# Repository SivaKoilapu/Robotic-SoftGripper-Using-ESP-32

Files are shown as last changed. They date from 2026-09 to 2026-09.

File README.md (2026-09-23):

# ESP32 IoT Robotic Arm Soft Gripper

An IoT-controlled robotic arm featuring a continuous-rotation pan/tilt base and a custom three-finger, tendon-driven mechanical soft gripper. The system is driven by an ESP32 and controlled remotely via the Blynk IoT platform.

## ⚙️ Hardware Architecture
* **Microcontroller:** ESP32
* **Actuation (Pan/Tilt):** Continuous Rotation Servos
* **Actuation (Gripper):** N20 Micro Gearmotor with Magnetic Encoder
* **Motor Driver:** TB6612FNG (For N20 bidirectional control)
* **Gripper Mechanism:** 3D-printed TPU mechanically-driven soft fingers, actuated by the N20 motor rotating a worm gear and follower.

## 💻 Software & Control Logic
The firmware is written in C++ and leverages `BlynkSimpleEsp32` for remote telemetry and control.

* **Asymmetric Joystick Mapping (Tilt Arm):** Continuous servos fighting gravity require highly specific PWM signals. The tilt arm uses an asymmetric mapping curve to distinguish between lifting against gravity, active braking, and powered descent.
* **Closed-Loop Gripper Control:** The N20 motor utilizes a custom PID-style interrupt loop reading the quadrature encoder. This allows the system to target precise rotational clicks (e.g., exactly 3 turns to fully close the tendons) and actively lock the brakes when target is reached.

## 📂 Repository Contents
* `/CAD` - Contains the SolidWorks part and assembly files (`.SLDPRT`, `.SLDASM`) for the arm and the TPU soft gripper, alongside `.STL` exports for immediate 3D printing.
* `/Firmware` - The Arduino IDE / PlatformIO compatible C++ code for the ESP32.

## 🚀 Setup & Installation
1. Flash the firmware to the ESP32.
2. Update the `ssid`, `pass`, and `BLYNK_AUTH_TOKEN` variables with your local credentials.
3. In the Blynk App, configure the datastreams:
   * **V0 (Joystick X):** Map to `-100 to 100` (Pan Base)
   * **V1 (Joystick Y):** Map to `-100 to 100` (Tilt Arm)
   * **V2 (Switch):** Map to `0 and 100` (Gripper Open/Close)

---
**Team:**<br> 
-Harshit Gupta<br>
-Kanav Gupta<br>
-SivaSankara Dasu Koilapu<br>
-Nikita Chitra

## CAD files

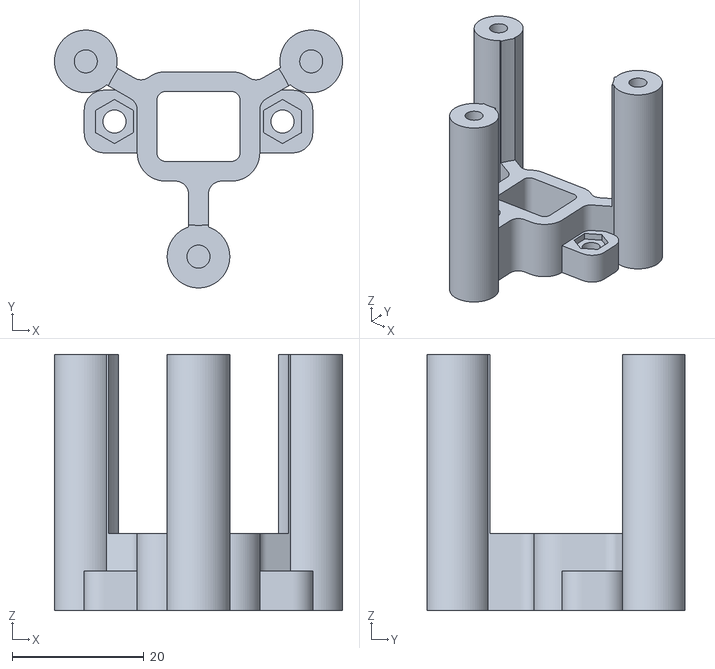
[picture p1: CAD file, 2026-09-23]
CAD/Gripper/Motor support.stl
43.7 x 39.1 x 38.9

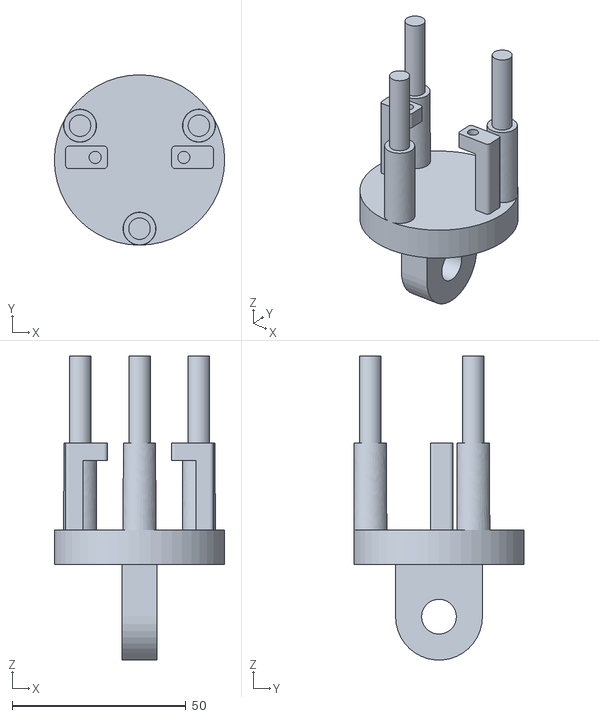
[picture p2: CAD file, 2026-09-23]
CAD/Pan Tilt/supporting mount.stl
49.0 x 49.0 x 87.5

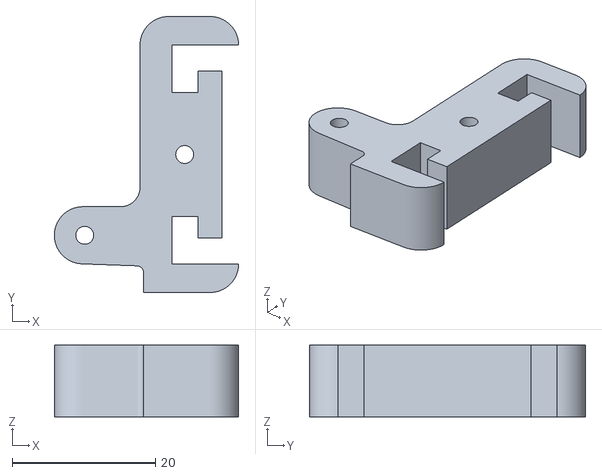
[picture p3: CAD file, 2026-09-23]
CAD/Gripper/Clamp.stl
25.8 x 38.6 x 10.0

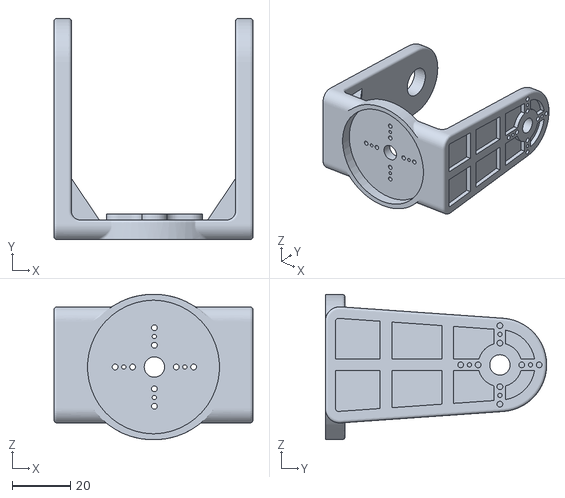
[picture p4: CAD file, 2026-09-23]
CAD/Pan Tilt/Holder.STL
68.4 x 76.1 x 50.0

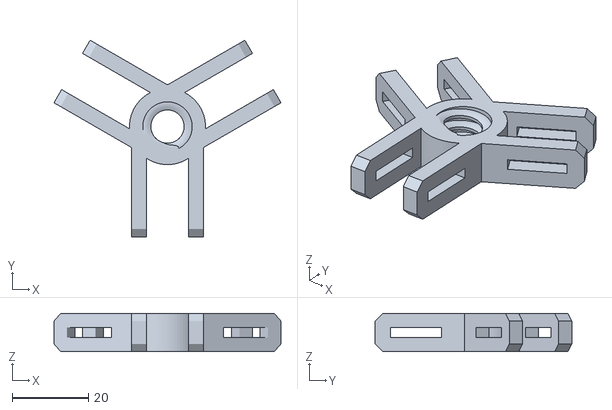
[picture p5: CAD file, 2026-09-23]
CAD/Gripper/Worm Follower.stl
59.7 x 51.7 x 10.0

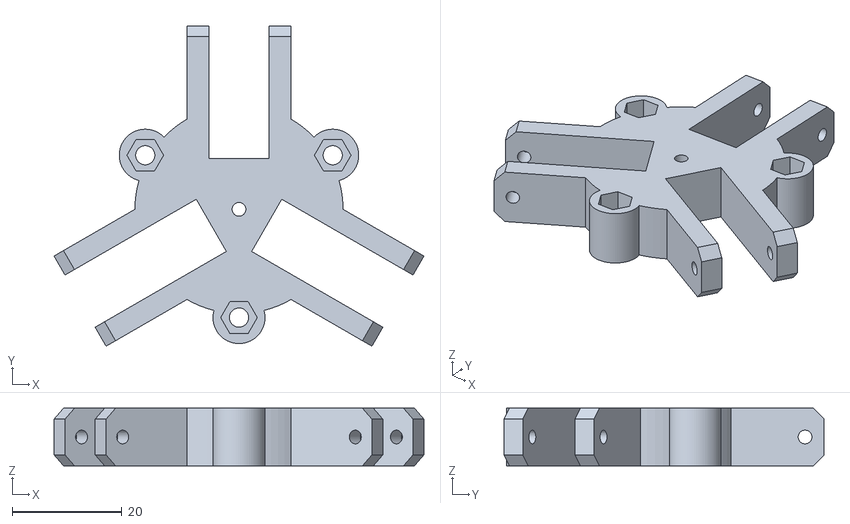
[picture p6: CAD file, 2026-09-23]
CAD/Gripper/Front base.stl
67.5 x 58.5 x 10.5

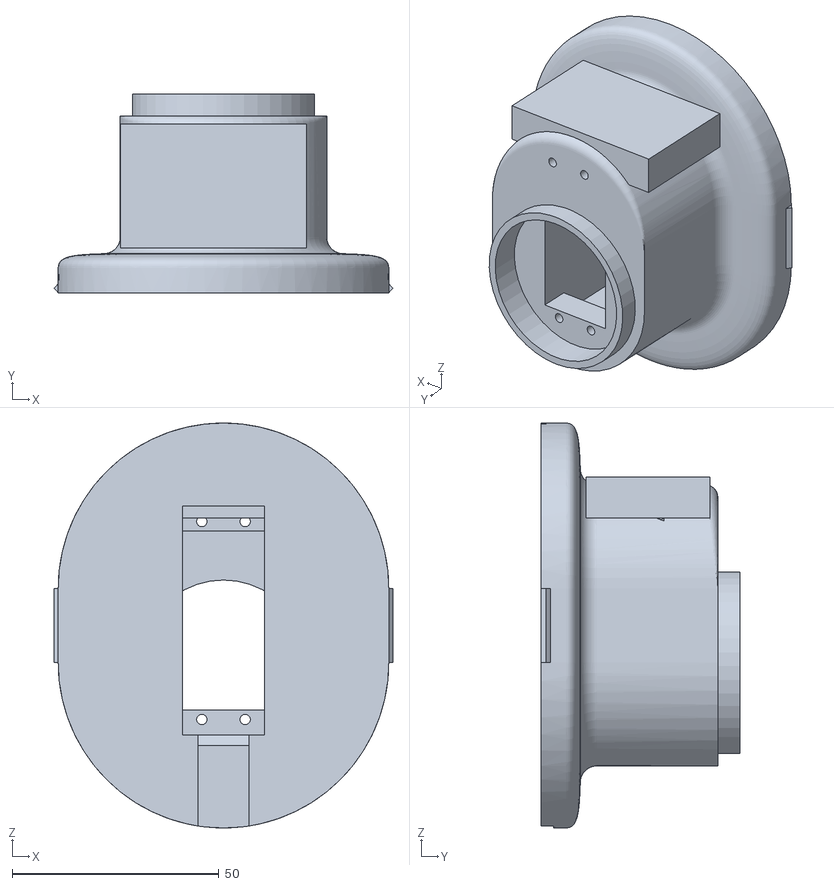
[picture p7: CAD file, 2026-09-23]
CAD/Pan Tilt/Base.STL
82.0 x 48.1 x 98.0

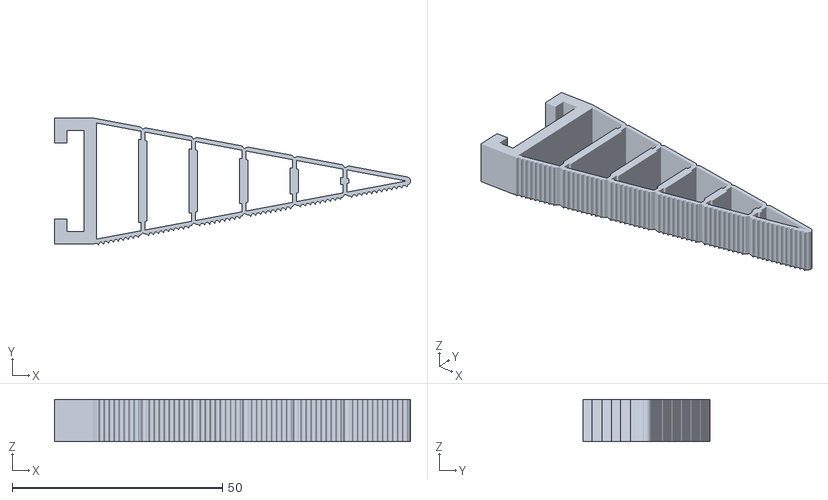
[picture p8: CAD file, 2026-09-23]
CAD/Gripper/fingers.stl
84.6 x 30.2 x 10.0

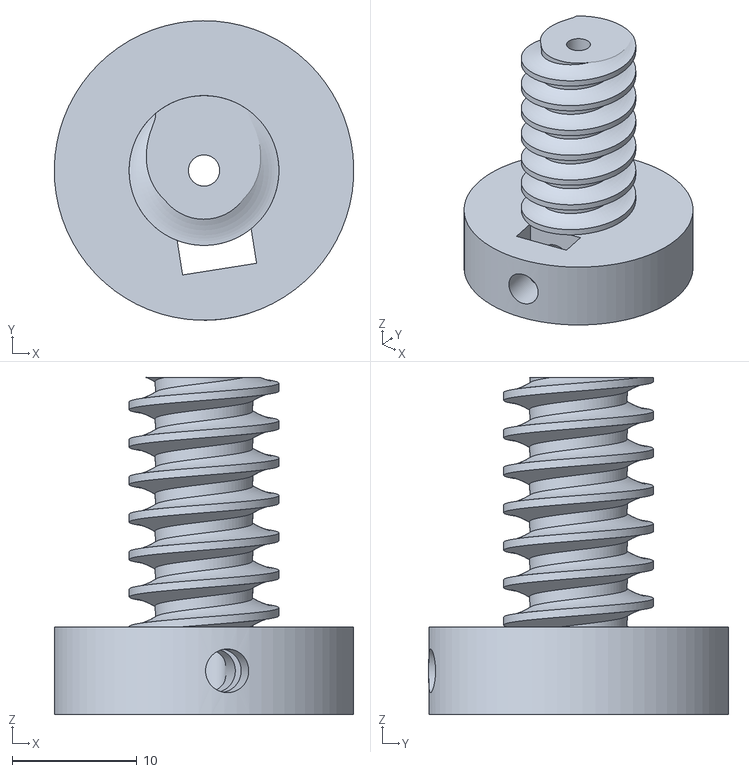
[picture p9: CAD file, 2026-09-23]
CAD/Gripper/Worm Gear.stl
24.0 x 24.0 x 27.0

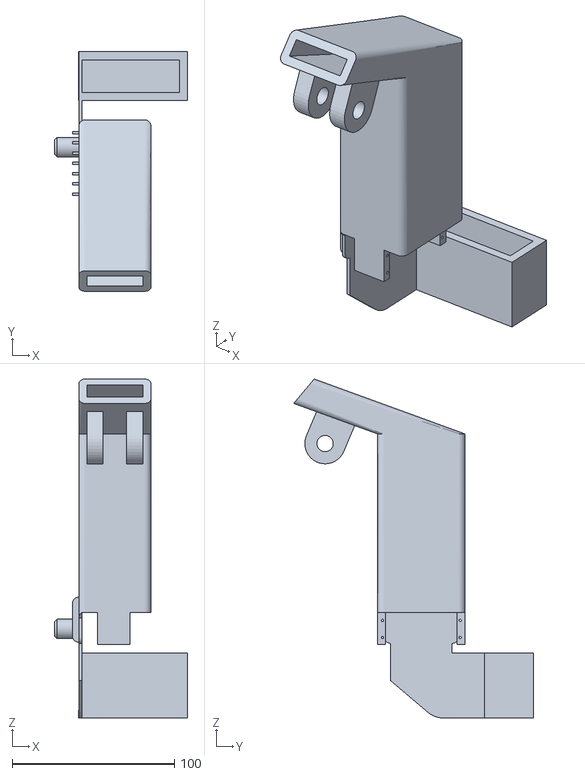
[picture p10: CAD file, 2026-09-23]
CAD/Pan Tilt/Arm.STL
81.9 x 147.6 x 208.9

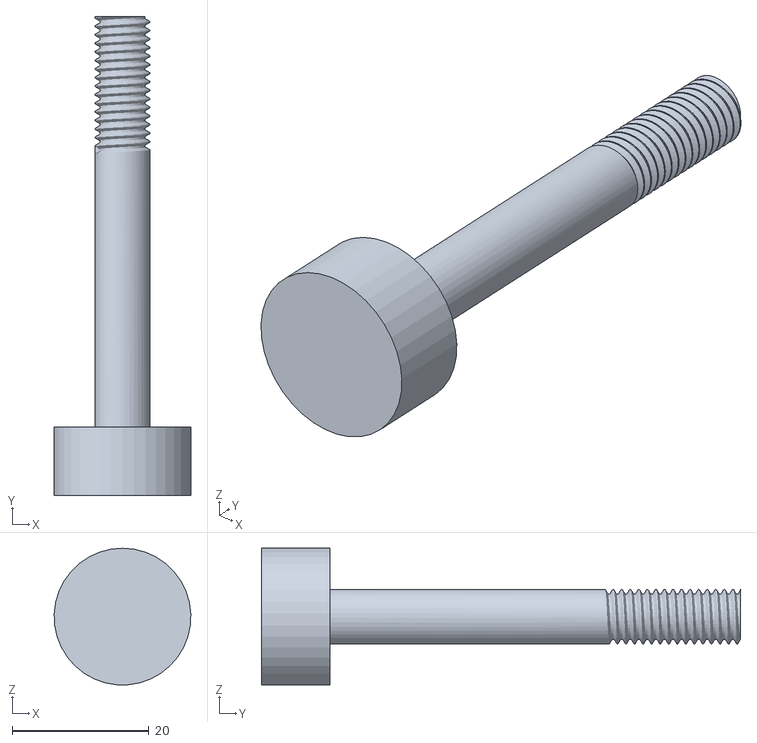
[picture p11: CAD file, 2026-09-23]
CAD/Pan Tilt/Bolt.STL
20.0 x 70.0 x 20.0

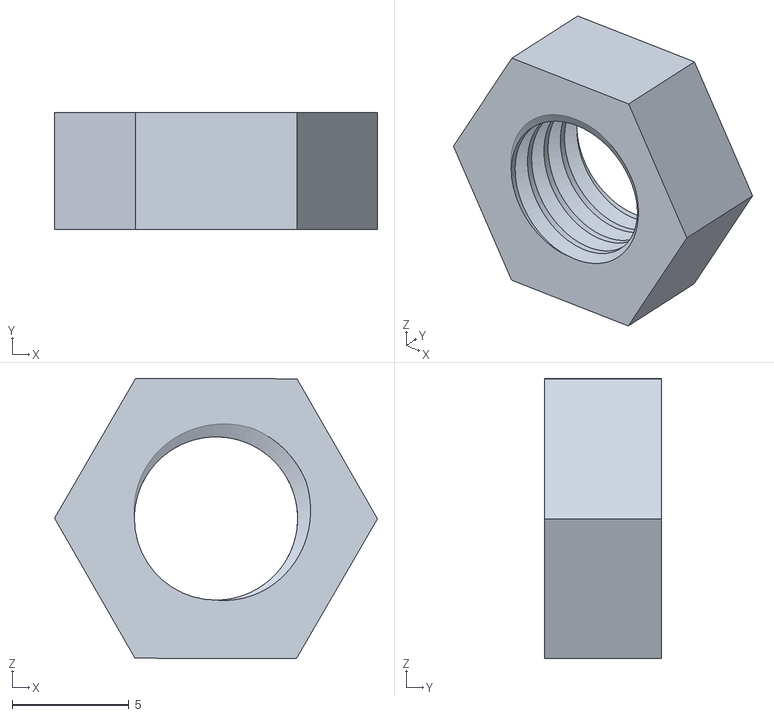
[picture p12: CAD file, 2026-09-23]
CAD/Pan Tilt/Nut.STL
13.9 x 5.00 x 12.0

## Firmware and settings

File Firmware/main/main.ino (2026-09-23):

#define BLYNK_TEMPLATE_ID "TMPL3nZPT9_pz"
#define BLYNK_TEMPLATE_NAME "Gripper Model with 360 Arm"
#define BLYNK_AUTH_TOKEN "63S8JMw-MCjBy4H8H5HToyI-dCxdp5cI"
#define BLYNK_PRINT Serial

#include <WiFi.h>
#include <BlynkSimpleEsp32.h>
#include <ESP32Servo.h>

char ssid[] = "O";
char pass[] = "password";

// --- SERVO PINS & OBJECTS ---
Servo servo1; // V0 Control (Pan Base)
Servo servo2; // V1 Control (Tilt Arm)
const int servo1Pin = 13;
const int servo2Pin = 25;

// If a servo "creeps" when the joystick is at 0
int neutralPoint = 95; 

// --- N20 MOTOR PINS (TB6612FNG) ---
const int AIN1 = 26;
const int AIN2 = 27;
const int PWMA = 14;

// --- ENCODER PINS ---
const int ENCODER_C1 = 32;
const int ENCODER_C2 = 33;

// --- CALIBRATED GRIPPER MATH ---
volatile long encoderCount = 0; // Live position
long targetPosition = 0; // Desired position

// Your exact hardware numbers!
float n_turns = 3;               
int CLICKS_PER_TURN = 1000; 
long fullyClosedPosition = n_turns * CLICKS_PER_TURN;

// The Interrupt Function for the Encoder
void IRAM_ATTR updateEncoder() {
  if (digitalRead(ENCODER_C2) == HIGH) {
    encoderCount++;
  } else {
    encoderCount--; 
  }
}

// ---------------------------------------------------------
// V0: Servo 1 (Joystick -100 to 100)
// ---------------------------------------------------------
BLYNK_WRITE(V0) {
  int throttle = param.asInt(); 
  int pwmSignal = map(throttle, -100, 100, 78, 102);
  Serial.println(pwmSignal);
  servo1.write(pwmSignal);
}
// ---------------------------------------------------------
// V1: Servo 2 (Joystick -100 to 100) - ASYMMETRIC MAPPING
// ---------------------------------------------------------
BLYNK_WRITE(V1) {
  int throttle = param.asInt(); 
  int pwmSignal;
  
  if (throttle < 0) {
    // LOWER HALF: -100 to -1 maps to 90 to 94
    pwmSignal = map(throttle, -100, -1, 90, 94); 
  } 
  else if (throttle > 0) {
    // UPPER HALF: 1 to 100 maps to 96 to 115
    pwmSignal = map(throttle, 1, 100, 96, 115); 
  } 
  else {
    // DEAD CENTER: Joystick is resting at exactly 0
    pwmSignal = 95; 
  }
  
  Serial.print("Joystick: ");
  Serial.print(throttle);
  Serial.print(" -> Asymmetric PWM: ");
  Serial.println(pwmSignal);
  
  servo2.write(pwmSignal);
}

// ---------------------------------------------------------
// V2: N20 Gripper (Switch 0 or 1)
// ---------------------------------------------------------
BLYNK_WRITE(V2) {
  int switchState = param.asInt(); 
  
  if (switchState == 100) {
    targetPosition = fullyClosedPosition;
    Serial.println("Closing Gripper to 3000...");
  } else if (switchState == 0) {
    targetPosition = 0;
    Serial.println("Opening Gripper to 0...");
  }
  else {
    Serial.println("Errors");
  }
}

void setup() {
  Serial.begin(115200);

  // --- SERVO SETUP ---
  ESP32PWM::allocateTimer(0);
  ESP32PWM::allocateTimer(1);
  servo1.setPeriodHertz(50); 
  servo2.setPeriodHertz(50); 
  servo1.attach(servo1Pin, 500, 2500); 
  servo2.attach(servo2Pin, 500, 2500); 
  
  // Force servos to a dead stop on startup
  servo2.write(neutralPoint);

  // --- N20 SETUP ---
  pinMode(AIN1, OUTPUT);
  pinMode(AIN2, OUTPUT);
  pinMode(PWMA, OUTPUT);
  pinMode(ENCODER_C1, INPUT_PULLUP);
  pinMode(ENCODER_C2, INPUT_PULLUP);
  attachInterrupt(digitalPinToInterrupt(ENCODER_C1), updateEncoder, RISING);

  // Reset gripper position
  encoderCount = 0; 
  targetPosition = 0;

  Serial.println("Connecting to Wi-Fi...");
  Blynk.begin(BLYNK_AUTH_TOKEN, ssid, pass);
  Serial.println("System Online! Awaiting Dashboard Commands.");
}

void loop() {
  Blynk.run(); 

  // --- CONTINUOUS CLOSED-LOOP GRIPPER CONTROL ---
  long error = targetPosition - encoderCount;
  
  // Tolerance: How close is "good enough" to stop the motor?
  int tolerance = 25; 
  int motorSpeed = 230; 

  if (abs(error) <= tolerance) {
    // Target reached. Lock the brakes!
    digitalWrite(AIN1, HIGH);
    digitalWrite(AIN2, HIGH);
    analogWrite(PWMA, 255); // Maximum braking force
    
  } else if (error > tolerance) {
    // Target is ahead: Spin forward
    digitalWrite(AIN1, HIGH);
    digitalWrite(AIN2, LOW);
    analogWrite(PWMA, motorSpeed);
    
  } else if (error < -tolerance) {
    // Target is behind: Spin reverse
    digitalWrite(AIN1, LOW);
    digitalWrite(AIN2, HIGH);
    analogWrite(PWMA, motorSpeed);
  }
  
  delay(10); 
}
// Contributed to the soft gripper development branch
